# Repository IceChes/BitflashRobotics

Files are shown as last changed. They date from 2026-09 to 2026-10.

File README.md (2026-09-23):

# What is this project?
Bitflash Robotics is an attempt to modernize combat robotics electronics. 

## Devices (see devices page for more information)
### Firefly

ESP32C3-based BLE combat robot receiver. Connects to a standard BLE game controller and controls all other robotic components. Also runs more complex compute loads if needed.

Has 2 snap (serial) ports, 1 servo port, and 1 Qwiic port. 

### Impulse

megaAVR-based brushed motor controller. Connects to one of Firefly's snap ports using a standard Qwiic/Stemma QT cable. Controls 2 brushed motors with short circuit protection and supplies 3.3v power to the robot's low voltage subsystem. 

## Standards
### BFR Packet Protocol (See Bitflash Robotics Arduino Library page for more information)

High speed structured protocol for writing sets of bytes over a standard UART bus to communicate with components. Due to its efficiency, it is able to run at extremely high speeds. Has basic error checking procedures to ensure safety and reliability in high-noise, high-intensity environments.

### Snap Serial (See Snap Serial page for more information)

Snap Serial (or just Snap) is simply UART over a Qwiic/Stemma QT port. This helps reduce connector size in the extremely tight electronics bays inside of combat robots. 

## Robots
### ???

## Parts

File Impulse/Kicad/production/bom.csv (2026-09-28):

Designator | Footprint | Quantity | Value | LCSC Part #
C1 | 0805 | 1 | 10uF
C10 | 0805 | 1 | 22uF
C11, C12, C2, C3, C4 | 0402 | 5 | 0.1uF
C9 | 0402 | 1 | 47pF
D1 | 0805 | 1 | LED
D2 | D_SOD-123F | 1 | 1.5A
J1 | PinSocket_1x02_P2.54mm_Vertical | 1 | Power
J2 | PinHeader_1x01_P2.54mm_Vertical | 1 | UPDI
J5 | QWIIC_SNAPSERIAL | 1 | PRT-14417
L2 | L_Changjiang_FTC201610S | 1 | 3.3uH
R1 | 0402 | 1 | 220
R2, R3 | 0402 | 2 | 0.2
R4 | 0402 | 1 | 135k
R5 | 0402 | 1 | 30k
R8 | 0402 | 1 | 100k
U1 | QFN-24-1EP_4x4mm_P0.5mm_EP2.6x2.6mm | 1 | ATtiny1617-M
U2 | SOT-563 | 1 | ~
U3, U4 | SOIC-8-1EP_3.9x4.9mm_P1.27mm_EP2.41x3.3mm | 2 | A4950E

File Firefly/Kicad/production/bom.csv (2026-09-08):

Designator | Footprint | Quantity | Value | LCSC Part #
D1, D2 | 0805 | 2 | LED
J1, J2, J3 | QWIIC_SNAPSERIAL | 3 | QWIIC/SNAPSERIAL
J4 | PinSocket_1x02_P2.54mm_Vertical | 1 | Conn_01x02_Pin
U1 | XIAO-ESP32C3 | 1 | XIAO-ESP32C3

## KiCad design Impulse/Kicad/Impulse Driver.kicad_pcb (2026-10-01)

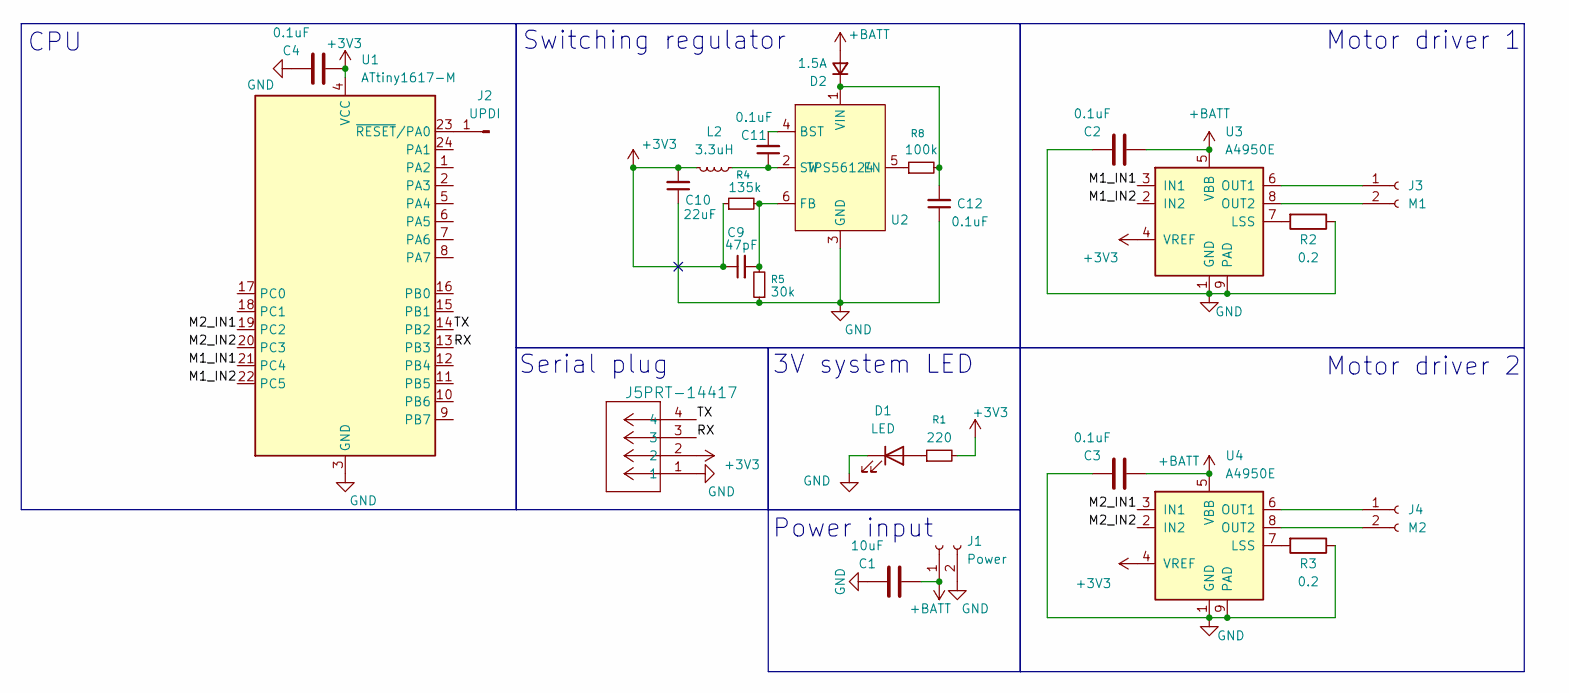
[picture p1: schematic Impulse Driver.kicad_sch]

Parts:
C1: 10uF; C_0805_2012Metric; LCSC C440198
C2, C3, C4, C11, C12: 0.1uF; C_0402_1005Metric; LCSC C14663
C9: 47pF; C_0402_1005Metric; LCSC C60137
C10: 22uF; C_0805_2012Metric; LCSC C602037
D1: LED; LED_0805_2012Metric; LCSC C965814
D2: 1.5A; D_SOD-123F
J1: Power; PinSocket_1x02_P2.54mm_Vertical
J2: UPDI; PinHeader_1x01_P2.54mm_Vertical
J3: M1; PinSocket_1x02_P2.54mm_Vertical
J4: M2; PinSocket_1x02_P2.54mm_Vertical
J5: PRT-14417; QWIIC_SNAPSERIAL
L2: 3.3uH; L_Changjiang_FTC201610S
R1: 220; R_0402_1005Metric; LCSC C2909336
R2, R3: 0.2; R_0402_1005Metric; LCSC C7467478
R4: 135k; R_0402_1005Metric; LCSC C2515705
R5: 30k; R_0402_1005Metric; LCSC C2909347
R8: 100k; R_0402_1005Metric; LCSC C25741
U1: ATtiny1617-M; QFN-24-1EP_4x4mm_P0.5mm_EP2.6x2.6mm; LCSC C1340514
U2: TPS56124; SOT-563
U3, U4: A4950E; SOIC-8-1EP_3.9x4.9mm_P1.27mm_EP2.41x3.3mm; LCSC C82404

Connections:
+3V3: C4.1, C9.1, C10.2, J5.2, L2.2, R1.2, R4.1, U1.4 (VCC), U3.4 (VREF), U4.4 (VREF)
+BATT: C1.1, C2.1, C3.1, D2.2 (A), J1.1, U3.5 (VBB), U4.5 (VBB)
/M1_IN1: U1.21 (PC4), U3.3 (IN1)
/M1_IN2: U1.22 (PC5), U3.2 (IN2)
/M2_IN1: U1.19 (PC2), U4.3 (IN1)
/M2_IN2: U1.20 (PC3), U4.2 (IN2)
/RX: J5.3, U1.13 (PB3)
/TX: J5.4, U1.14 (PB2)
GND: C1.2, C2.2, C3.2, C4.2, C10.1, C12.1, D1.1 (K), J1.2, J5.1, R2.1, R3.1, R5.1, U1.3 (GND), U1.25 (GND), U2.3 (GND), U3.1 (GND), U3.9 (PAD), U4.1 (GND), U4.9 (PAD)
unnamed: D1.2 (A), R1.1
unnamed: C12.2, D2.1 (K), R8.2, U2.1 (VIN)
unnamed: J2.1 (Pin_1_1), U1.23 (~RESET/PA0)
unnamed: J3.1, U3.6 (OUT1)
unnamed: J3.2, U3.8 (OUT2)
unnamed: J4.1, U4.6 (OUT1)
unnamed: J4.2, U4.8 (OUT2)
unnamed: C11.2, U2.4 (BST)
unnamed: R8.1, U2.5 (EN)
unnamed: C9.2, R4.2, R5.2, U2.6 (FB)
unnamed: C11.1, L2.1, U2.2 (SW)
unnamed: R2.2, U3.7 (LSS)
unnamed: R3.2, U4.7 (LSS)

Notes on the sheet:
Serial plug
Motor driver 2
CPU
Switching regulator
Power input
3V system LED
Motor driver 1

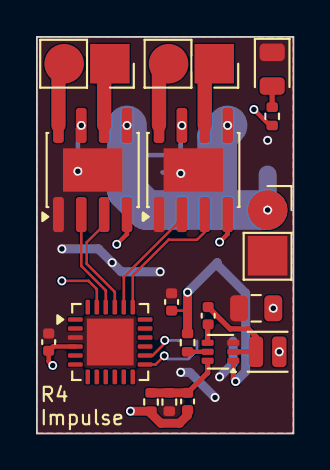
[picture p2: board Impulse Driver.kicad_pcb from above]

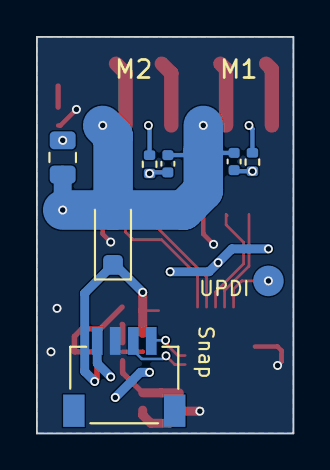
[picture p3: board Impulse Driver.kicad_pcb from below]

Board: 2 copper layers, 14.2 x 22.0 mm, 26 parts (7 on the bottom side), 22 nets.

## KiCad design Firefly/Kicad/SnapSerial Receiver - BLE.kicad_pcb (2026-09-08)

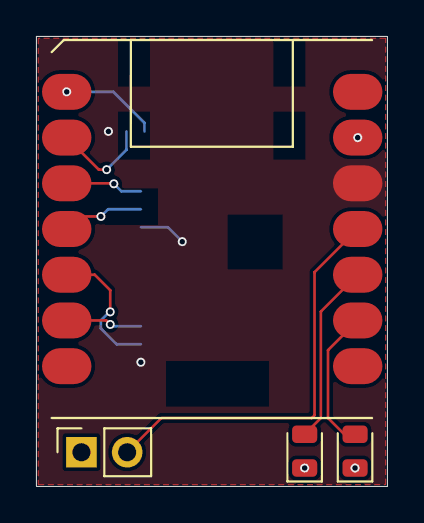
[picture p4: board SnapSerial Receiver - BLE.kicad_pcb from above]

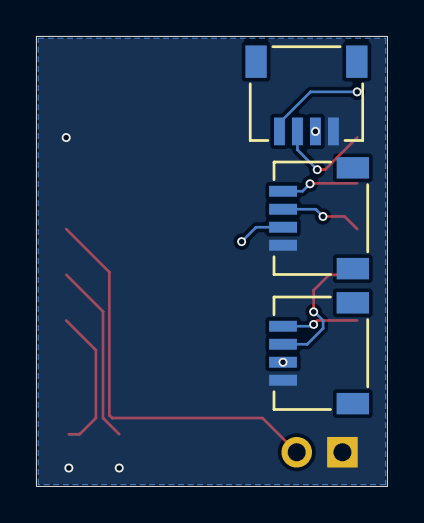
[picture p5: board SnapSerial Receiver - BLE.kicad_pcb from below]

Board: 2 copper layers, 19.5 x 25.0 mm, 7 parts (3 on the bottom side), 11 nets.

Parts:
D1, D2: LED; LED_0805_2012Metric
J1, J2, J3: QWIIC/SNAPSERIAL; QWIIC_SNAPSERIAL
J4: Conn_01x02_Pin; PinSocket_1x02_P2.54mm_Vertical
U1: XIAO-ESP32C3

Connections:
+3V3: J1.2, J2.2, J3.2, U1.12 (3V3)
/ESC: J4.2, U1.11 (PA6_A10_D10_MOSI)
/SCL: J3.4, U1.6 (PA9_A5_D5_SCL)
/SDA: J3.3, U1.5 (PA8_A4_D4_SDA)
/SSRX1: J1.4, U1.1 (PA02_A0_D0)
/SSRX2: J2.4, U1.3 (PA10_A2_D2)
/SSTX1: J1.3, U1.2 (PA4_A1_D1)
/SSTX2: J2.3, U1.4 (PA11_A3_D3)
GND: D1.1 (K), D2.1 (K), J1.1, J2.1, J3.1, J4.1, U1.13 (GND)
unnamed: D1.2 (A), U1.10 (PA5_A9_D9_MISO)
unnamed: D2.2 (A), U1.9 (PA7_A8_D8_SCK)

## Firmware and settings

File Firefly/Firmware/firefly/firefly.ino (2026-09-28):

#include <bfr_provisions.h>
#include <Bluepad32.h>
#include <Servo.h>
#include <CRC8.h>
#include <HardwareSerial.h>

#include "config.h"
#include "functions.h"


//timer vars
unsigned long timer;
unsigned long last_motor_1_active;
unsigned long last_motor_2_active;
unsigned long last_button_press;
unsigned long last_esc_update_time;
unsigned long last_debug_update;

//control vars
int esc_value = 1000;
int target_esc_value;
int motor_1_value;
int motor_2_value;
bool motor_1_active;
bool motor_2_active;
bool inverted = false;
bool weapon_locked = false;



//data checksum item
CRC8 crc_1;
CRC8 crc_2;



HardwareSerial DriverSerial(0);     //motor drivers are to be connected to the driver port
HardwareSerial AccessorySerial(1);  //accessory modules are to be connected to the accessory port



Servo weapon_control;



//MAC addresses
//uint8_t controller_mac[6] = { 0xF2, 0x8D, 0x95, 0xD5, 0x01, 0xE6 };  //stadia
//uint8_t controller_mac[6] = { 0xC8, 0x3F, 0x26, 0x8D, 0xE6, 0x28 }; //xbox



//data controls
DataStream driver(IMPULSE_DEVICE_ADDRESS, &DriverSerial);
DataStream accessory(IMPULSE_DEVICE_ADDRESS, &AccessorySerial);

uint8_t driver_return_code;
uint8_t accessory_return_code;



//input data structs
PacketData d_driver;
PacketData d_accessory;



enum drive_mode {
  IMPULSE
};
drive_mode current_drive_mode = CONFIG_DRIVE_TYPE;



enum weapon_mode {
  NONE,
  BRUSHLESS
};
weapon_mode current_weapon_mode = CONFIG_WEAPON_TYPE;



void setup() {

  assign(FIREFLY_DEVICE_ADDRESS, FIREFLY_EXPECTED_COMMAND_MAXIMUM);

  Serial.begin(115200);
  Serial.println("INFO: Serial initialized.");

  //serial setup
  digitalWrite(PIN_SNAP_1_RX, 0);
  digitalWrite(PIN_SNAP_1_TX, 0);
  digitalWrite(PIN_SNAP_2_RX, 0);
  digitalWrite(PIN_SNAP_2_TX, 0);
  Serial.begin(115200);
  Serial.println("BLUEPAD: Activating bluepad...");
  BP32.setup(&onConnectedController, &onDisconnectedController);
  Serial.println("BLUEPAD: Controller should be connected.");

  delay(3000);
  DriverSerial.begin(115200, SERIAL_8N1, PIN_SNAP_1_RX, PIN_SNAP_1_TX);
  AccessorySerial.begin(115200, SERIAL_8N1, PIN_SNAP_2_RX, PIN_SNAP_2_TX);


  //impulse setup
  if (current_drive_mode == IMPULSE) {
    if (USER_IMPULSE_RESET_ON_BOOT) {
      driver.sendPacket(IMPULSE_COMMAND_RESET, 0);
    }

    driver.sendPacket(IMPULSE_COMMAND_SET_CURVE, USER_IMPULSE_CURVE_LEVEL);

    if (USER_IMPULSE_BRAKE) {
      driver.sendPacket(IMPULSE_COMMAND_SET_BRAKE, true);
      driver.sendPacket(IMPULSE_COMMAND_SET_BRAKE_TIMEOUT, USER_BRAKE_TIMEOUT);
    } else {
      driver.sendPacket(IMPULSE_COMMAND_SET_BRAKE, false);
    }

    if (USER_IMPULSE_BRAKE_ON_STOP) {
      driver.sendPacket(IMPULSE_COMMAND_SET_FAIL_BRAKE, true);
    } else {
      driver.sendPacket(IMPULSE_COMMAND_SET_FAIL_BRAKE, false);
    }
  }
}





void loop() {



  //update timer
  timer = millis();



  //update snap1 packet
  while (DriverSerial.available()) {
    if (driver.receiveAndAssign(&d_driver, &driver_return_code)) {
      if (driver_return_code == GLOBAL_PACKET_ERROR_NONE) {
        handleInboundData(d_driver);
      } else if (driver_return_code != GLOBAL_PACKET_ERROR_NONE && USER_VERBOSE_LOGGING) {
        Serial.println("WARN: got garbled packet from driver with error code " + String(driver_return_code));
      }
    }
  }

  while (AccessorySerial.available()) {
    if (accessory.receiveAndAssign(&d_accessory, &accessory_return_code)) {
      if (accessory_return_code == GLOBAL_PACKET_ERROR_NONE) {
        handleInboundData(d_accessory);
      } else if (accessory_return_code != GLOBAL_PACKET_ERROR_NONE && USER_VERBOSE_LOGGING) {
        Serial.println("WARN: got garbled packet from accessory with error code " + String(accessory_return_code));
      }
    }
  }



  //process the controller data if there is new controller data.
  data_updated = BP32.update();
  if (data_updated) {
    processControllers();
  }



  //Motor inverts
  if (USER_INVERT_MOTOR_1) {
    inv_ls = map(ls, 509, -509, -509, 509);
  } else {
    inv_ls = ls;
  }

  if (USER_INVERT_MOTOR_2) {
    inv_rs = map(rs, 509, -509, -509, 509);
  } else {
    inv_rs = rs;
  }


  //Impulse driver handling
  if (current_drive_mode == IMPULSE) {
    if (used_ls > 100) {
      driver.sendPacket(IMPULSE_COMMAND_CHANNEL_1_FORWARDS, map(used_ls, 100, 509, 0, USER_MOTOR_1_MAXIMUM_SPEED));
    } else if (used_ls < -100) {
      driver.sendPacket(IMPULSE_COMMAND_CHANNEL_1_BACKWARDS, map(used_ls, -100, -509, 0, USER_MOTOR_1_MAXIMUM_SPEED));
    } else {
      driver.sendPacket(IMPULSE_COMMAND_CHANNEL_1_STOP, 0);
    }

    if (used_rs > 100) {
      driver.sendPacket(IMPULSE_COMMAND_CHANNEL_2_FORWARDS, map(used_rs, 100, 509, 0, USER_MOTOR_2_MAXIMUM_SPEED));
    } else if (used_rs < -100) {
      driver.sendPacket(IMPULSE_COMMAND_CHANNEL_2_BACKWARDS, map(used_rs, -100, -509, 0, USER_MOTOR_2_MAXIMUM_SPEED));
    } else {
      driver.sendPacket(IMPULSE_COMMAND_CHANNEL_2_STOP, 0);
    }
  }


  //inversion handling. this logic will work regardless of what esc is selected
  if (inverted) {
    used_ls = inv_rs;
    used_rs = inv_ls;
    if (dpad_state == 1) {
      inverted = false;
      rumble(200, 255, 0, myControllers[0]);
      last_button_press = timer;
    }
  } else if (!inverted) {
    used_ls = map(inv_ls, -509, 509, 509, -509);
    used_rs = map(inv_rs, -509, 509, 509, -509);
    if (dpad_state == 2) {
      inverted = true;
      rumble(200, 0, 255, myControllers[0]);
      last_button_press = timer;
    }
  }



  if (current_weapon_mode == BRUSHLESS) {
    if (target_esc_value > esc_value && (timer - last_esc_update_time > 1)) {
      esc_value += USER_WEAPON_RATE_LIMIT;
      last_esc_update_time = timer;
    } else if (target_esc_value < esc_value && (timer - last_esc_update_time > 1)) {
      esc_value -= USER_WEAPON_RATE_LIMIT;
      last_esc_update_time = timer;
    }

    //Toggle the throttle lock if A is pressed.
    if (rb && (timer - last_button_press > 200)) {
      weapon_locked = !weapon_locked;
      rumble(200, 255, 0, myControllers[0]);
      last_button_press = timer;
    }

    //If the throttle is locked, just make the target ESC value the current ESC value
    if (weapon_locked) {
      target_esc_value = esc_value;
    } else {  //Otherwise, map RT as usual.
      target_esc_value = map(rt, 0, 1020, 1000, USER_WEAPON_MAXIMUM_SPEED);
    }

    weapon_control.write(PIN_ESC, esc_value);
  }



  if ((timer - last_debug_update > USER_DEBUG_UPDATE_INTERVAL) && USER_VERBOSE_LOGGING) {
    if (controller_connected) {
      Serial.println("INFO: Controller connected.");
    }
    else{
      Serial.println("WARN: Controller not connected!");
    }
    last_debug_update = timer;
  }
}

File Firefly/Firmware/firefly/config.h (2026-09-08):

#include <Bluepad32.h>
#include <Servo.h>
#include <HardwareSerial.h>
#include "CRC8.h"

#define CONFIG_WEAPON_TYPE BRUSHLESS  //only BRUSHLESS or NONE supported
#define CONFIG_DRIVE_TYPE IMPULSE     //only IMPULSE supported
#define CONFIG_ACC_TYPE NONE          //not supported yet
#define CONFIG_I2C_TYPE NONE          //not supported yet
#define USER_WEAPON_RATE_LIMIT 5        //number of PPM the servo signal can change per ms. 1 = full speed to stop in 1 second.
#define USER_INVERT_MOTOR_1 false
#define USER_INVERT_MOTOR_2 false
#define USER_BRAKE_TIMEOUT 100
#define USER_DEBUG_UPDATE_INTERVAL 1000

#define USER_VERBOSE_LOGGING true

#define USER_IMPULSE_CURVE_LEVEL 100       //0 for off, 1-3 for lo-hi
#define USER_IMPULSE_BRAKE true     //0 for no brake, 1-3 for lo-hi
#define USER_IMPULSE_BRAKE_ON_STOP true     //0 for no brake, 1-3 for lo-hi
#define USER_IMPULSE_RESET_ON_BOOT true  //reset the impulse driver on every reciever bootup

#define USER_MOTOR_1_MAXIMUM_SPEED 255
#define USER_MOTOR_2_MAXIMUM_SPEED 255
#define USER_WEAPON_MAXIMUM_SPEED 2000

#define PIN_SNAP_1_RX 9
#define PIN_SNAP_1_TX 10
#define PIN_SNAP_2_RX 6
#define PIN_SNAP_2_TX 7
#define PIN_ESC 2
/*
#define INTERNAL_DEVICE_ADDRESS FIREFLY_DEVICE_ADDRESS
#define INTERNAL_DEVICE_EXPECTED_COMMAND_MAXIMUM FIREFLY_EXPECTED_COMMAND_MAXIMUM
*/

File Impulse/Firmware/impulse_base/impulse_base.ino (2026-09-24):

#include <CRC8.h>
#include <bfr_provisions.h>
#include <HardwareSerial.h>

#include "config.h"
#include "functions.h"

//timers
unsigned long timer;
unsigned long last_timer;
unsigned long last_packet;
unsigned long last_motor_1_active;
unsigned long last_motor_2_active;

//settings
int curve_exponent;
int motor_1_maximum_speed;
int motor_2_maximum_speed;
bool brake_enabled;
unsigned int brake_timeout;
bool failsafe_brake;

//motor controls
bool motor_1_active;
bool motor_2_active;
MotorControls m1;
MotorControls m2;

//inbound datastream controls

DataStream host(FIREFLY_DEVICE_ADDRESS);
PacketData d;
uint8_t packet_code;

//initialize crc
CRC8 crc;



void setup() {

  assign(IMPULSE_DEVICE_ADDRESS, IMPULSE_EXPECTED_COMMAND_MAXIMUM);

  Serial.begin(115200);
  Serial.setTimeout(50);

  //reset everything to default values
  timer = 0;
  last_timer = 0;
  curve_exponent = 0;
  brake_timeout = 100;
  brake_enabled = true;
  failsafe_brake = true;
  motor_1_maximum_speed = USR_MOTOR_1_MAXIMUM_SPEED;
  motor_2_maximum_speed = USR_MOTOR_2_MAXIMUM_SPEED;

  crc.restart();

  host.sendPacket(IMPULSE_OUTBOUND_INFO, GLOBAL_INFO_DEVICE_READY);
}

void loop() {
  timer = millis();

  m1.curve_exponent = curve_exponent;
  m2.curve_exponent = curve_exponent;

  m1.maximum_speed = motor_1_maximum_speed;
  m2.maximum_speed = motor_2_maximum_speed;



  while (Serial.available()) {
    if (host.receiveAndAssign(&d, &packet_code)) {
      last_packet = timer;
      //if this was a really complicated or nested switch, i'd use a LUT, but this is just one long-ish thing
      switch (d.command) {
        case IMPULSE_COMMAND_SET_CURVE:
          curve_exponent = d.payload;
          break;

        case IMPULSE_COMMAND_SET_BRAKE:
          brake_enabled = d.payload;
          break;

        case IMPULSE_COMMAND_SET_FAIL_BRAKE:
          failsafe_brake = d.payload;
          break;

        case IMPULSE_COMMAND_SET_BRAKE_TIMEOUT:
          brake_timeout = d.payload;
          break;

        case IMPULSE_COMMAND_SET_CHANNEL_1_MAXIMUM_SPEED:
          motor_1_maximum_speed = d.payload;
          break;

        case IMPULSE_COMMAND_SET_CHANNEL_2_MAXIMUM_SPEED:
          motor_2_maximum_speed = d.payload;
          break;

        case IMPULSE_COMMAND_CHANNEL_1_FORWARDS:
          m1.payload = d.payload;
          analogWrite(PIN_CHANNEL_1_A, calculatePWM(m1));
          digitalWrite(PIN_CHANNEL_1_B, 0);

          motor_1_active = true;
          last_motor_1_active = timer;
          break;

        case IMPULSE_COMMAND_CHANNEL_1_BACKWARDS:
          m1.payload = d.payload;
          digitalWrite(PIN_CHANNEL_1_A, 0);
          analogWrite(PIN_CHANNEL_1_B, calculatePWM(m1));

          motor_1_active = true;
          last_motor_1_active = timer;
          break;

        case IMPULSE_COMMAND_CHANNEL_2_FORWARDS:
          m2.payload = d.payload;
          analogWrite(PIN_CHANNEL_2_A, calculatePWM(m2));
          digitalWrite(PIN_CHANNEL_2_B, 0);

          motor_2_active = true;
          last_motor_2_active = timer;
          break;

        case IMPULSE_COMMAND_CHANNEL_2_BACKWARDS:
          m2.payload = d.payload;
          digitalWrite(PIN_CHANNEL_2_A, 0);
          analogWrite(PIN_CHANNEL_2_B, calculatePWM(m2));

          motor_2_active = true;
          last_motor_2_active = timer;
          break;

        case IMPULSE_COMMAND_CHANNEL_1_STOP:
          if (brake_enabled && (timer - last_motor_1_active > brake_timeout)) {
            digitalWrite(PIN_CHANNEL_1_A, 1);
            digitalWrite(PIN_CHANNEL_1_B, 1);
          } else {
            digitalWrite(PIN_CHANNEL_1_A, 0);
            digitalWrite(PIN_CHANNEL_1_B, 0);
          }
          break;

        case IMPULSE_COMMAND_CHANNEL_2_STOP:
          if (brake_enabled && (timer - last_motor_2_active > brake_timeout)) {
            digitalWrite(PIN_CHANNEL_2_A, 1);
            digitalWrite(PIN_CHANNEL_2_B, 1);
          } else {
            digitalWrite(PIN_CHANNEL_2_A, 0);
            digitalWrite(PIN_CHANNEL_2_B, 0);
          }
          break;

        case IMPULSE_COMMAND_STOP_ALL:
          if (brake_enabled) {
            digitalWrite(PIN_CHANNEL_1_A, 1);
            digitalWrite(PIN_CHANNEL_1_B, 1);
            digitalWrite(PIN_CHANNEL_2_A, 1);
            digitalWrite(PIN_CHANNEL_2_B, 1);
          } else {
            digitalWrite(PIN_CHANNEL_1_A, 0);
            digitalWrite(PIN_CHANNEL_1_B, 0);
            digitalWrite(PIN_CHANNEL_2_A, 0);
            digitalWrite(PIN_CHANNEL_2_B, 0);
          }
          break;

        case IMPULSE_COMMAND_RESET:
          timer = 0;
          last_timer = 0;
          curve_exponent = 0;
          brake_enabled = true;
          brake_timeout = 100;
          failsafe_brake = true;
          motor_1_maximum_speed = USR_MOTOR_1_MAXIMUM_SPEED;
          motor_2_maximum_speed = USR_MOTOR_2_MAXIMUM_SPEED;
      }
    }
    if (packet_code != 0) {
      host.sendPacket(IMPULSE_OUTBOUND_ERROR, packet_code);
    }
  }
  if (timer - last_packet > USR_SERIAL_SAFETY_TIMEOUT) {
    digitalWrite(PIN_CHANNEL_1_A, brake_enabled);
    digitalWrite(PIN_CHANNEL_1_B, brake_enabled);
    digitalWrite(PIN_CHANNEL_2_A, brake_enabled);
    digitalWrite(PIN_CHANNEL_2_B, brake_enabled);
  }
}

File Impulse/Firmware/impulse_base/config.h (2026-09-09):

//motor controller pins
#define PIN_CHANNEL_1_A PIN_PA4
#define PIN_CHANNEL_1_B PIN_PA5
#define PIN_CHANNEL_2_A PIN_PB1
#define PIN_CHANNEL_2_B PIN_PB0



//user settings
#define USR_MOTOR_1_MAXIMUM_SPEED 255
#define USR_MOTOR_2_MAXIMUM_SPEED 255

//serial safety timeout
#define USR_SERIAL_SAFETY_TIMEOUT 10000

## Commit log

2026-09-08 these should just be in one repo tbh
    [Impulse Driver.kicad_pcb, Impulse Driver.kicad_sch, SnapSerial Receiver - BLE.kicad_pcb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]
2026-09-09 we have a library! it probably doesn't work yet though.
    [bfr_provisions.h, config.h, firefly.ino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]
2026-09-24 work on the impulse bom
    [Impulse Driver.kicad_sch]
2026-09-28 fab files for impulse + example code
    [Impulse Driver.kicad_pcb, bom.csv, designators.csv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]
2026-10-01 fix severe error with low current 12v lines
    [Impulse Driver.kicad_pcb, Impulse Driver.kicad_sch]
